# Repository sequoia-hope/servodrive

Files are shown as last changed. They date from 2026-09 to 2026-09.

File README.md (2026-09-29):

# servodrive

A round, motor-mounted servodrive: two Ø65 mm boards stacked on the back of a
brushless motor, with a magnetic rotary encoder on the shaft axis.

**Status: board A captured, placed and routed. 136 parts, 87 nets,
425 pin connections, every one of them made. DRC- and ERC-clean, and
KiCad's own extracted netlist matches the intended one connection for
connection. Re-routed 2026-09-22 with four of the simulation's changes
([below](#the-2026-09-22-changes)); board B is still an outline.
Board S, the single-board variant, captured, placed and routed 2026-09-23
from the same generators, re-routed the same day with TI's buck parts, and
re-placed and re-routed 2026-09-24 with an XT30 for the bus
([below](#board-s-one-board)).**

- **[spec.html](spec.html)** — the specification
- **[index.html](index.html)** — status, decisions, open questions; board A in the viewer (PCB and 3D tabs)
- **[single.html](single.html)** — board S, the single-board variant: captured, placed and routed, with the same viewer (SCH, PCB and 3D)

The pages are styled after Altium 365's workspace: a dark frame with the
project tree on the left, built by `shell.js` from each page's own headings.
The board viewer on the two board pages is
[pcbview](https://github.com/sequoia-hope/pcbview)'s (which began as this
project's own; `tools/regen.py` runs it from `~/Software/pcbview`):
`pcbview.toml` says what it shows, and `python3 tools/regen.py --board a|s`
builds it into `viewer/` and writes it into the page between
`<!-- pcbview:begin -->` and `<!-- pcbview:end -->`.
`viewer/a.html` and `viewer/s.html` are the same viewers filling the window.

Online at <https://sequoia-hope.github.io/servodrive/> (GitHub Pages, from
the root of `main`: the pages are plain files with relative links, and
`.nojekyll` keeps them that way). Served locally: `proj up servodrive`, then
`proj url servodrive` for the address.

## What it is

| | |
|---|---|
| Form | Two Ø65 mm round boards. The motor board bolts to the encoder's 4 × M3 pattern; the power/IO board to six perimeter M2.5. |
| Sections | Three 60° phase cells **adjacent**, 0–180°, then three 60° wedges. The CPU sits in the middle wedge, as far from the switching as a round board allows. |
| Encoder | MT6701 on the shaft axis, SSI to the CPU on the same board. No cable, no line drivers, no encoder port. |
| Bus | 60 V nominal, **12 V minimum**, 80 V silicon, TVS breakdown 71–79 V; XT30 |
| Phase current | **20 A RMS per phase, in bursts** — normal running is well below it, and no fins are planned (§4) |
| CPU | RP2350A, QFN-60 |
| Sensing | Two inline 1.0 mΩ shunts (2 × 2 mΩ) + **INA241A3** at 50 V/V = 50 mV/A, third phase reconstructed; bus voltage; FET temperature |
| Gate drive | EG2103 on a 12 V rail (LCSC C480654, 2,225 in stock, MOQ 5, $0.19) — interlock + 560 ns dead time |
| I/O | USB-C with full PD — a 20 V contract feeds VMOT; full-duplex RS-485 on two chained ports |

## The design point is 20 A RMS, and that word matters

Draft 0.2 used "20 A" for two different quantities: the thermal budget quoted
20 A **RMS per phase**, and the sense chain quoted ±20.6 A **instantaneous**.
Those differ by √2, so the sense chain clipped at 14.6 A RMS — it could not have
closed a current loop at the design point. One number now, and everything is
sized against it:

| | |
|---|---|
| Design point | 20 A RMS per phase — a burst figure since 2026-09-22, not a continuous rating |
| Peak the chain must see | 28.3 A |
| Sense full scale | ±29.0 A, worst-case output swing — 2.5% over the peak, see below |
| Board A dissipation | 10.7 W |
| Heatsink it would need to be continuous | ≤ 6.7 K/W, ≥ 100 cm² of external surface — not built |

## Current sensing

Full scale is set by the shunt. Keep this table, the schematic and the firmware
`SHUNT_RESISTOR` define pointed at each other — the sister project's F-14 is
exactly this drifting apart.

| Shunt (per sensed phase) | Gain | V/A | Measurable range |
|---|---|---|---|
| 1.0 mΩ (2 × 2 mΩ 2010) | 50 V/V | 0.050 | ±29.0 A |
| 2 mΩ (one desoldered) | 50 V/V | 0.100 | ±14.5 A |

Phase C is reconstructed as `Ic = -(Ia + Ib)`. Its two shunt footprints are
fitted with 0 Ω links so all three phases have the same series resistance.

Full scale is against the datasheet's **worst-case** output swing, V<sub>S</sub> − 0.2 V,
not the 0.07 V typical — that is what makes ±29.0 A rather than ±32 A, and it is
the number the design point has to clear. It does, by 2.5%.

**This took three goes.** Draft 0.2's 1.6 mΩ gave 80 mV/A to match the sister
project's firmware scaling, and ±20.6 A of full scale against a 28.3 A peak: it
would have clipped on every cycle above 14.6 A RMS. The first correction, 1.0 mΩ,
used the typical swing figure and had 2.5% of margin, which is not margin. 0.8 mΩ
(2 × 1.6 mΩ) survived the datasheet, and its precision mode landed on the sister
project's 80 mV/A. Then sourcing (2026-09-24) found no 1.6 mΩ 2010 at LCSC or
JLCPCB — 1 and 2 mΩ, nothing between — and the pair became 2 × 2 mΩ: back at
1.0 mΩ and its 2.5%, taken knowingly. The stocked alternative, 2 × 1 mΩ, reads
±58 A at 25 mV/A. Neither mode reproduces the sister project's 80 mV/A now, so
its firmware constants do not carry across.

**And the part number changed.** The 50 V/V grade of INA241 is **A3**, not A2.
INA240 numbers its gains A1 = 20, A2 = 50; INA241 numbers them A1 = 10, A2 = 20,
A3 = 50. Draft 0.2 carried the INA240 mapping across and specified a 20 V/V part
for a 50 V/V job.

## Relationship to rp2350-motor-controller

The sister project at `~/pcb/rp2350-motor-controller` supplies the MT6701
encoder circuit and its mount pattern (`hardware/encoder`), the power-stage part
choices, and a findings register that this board inherits the conclusions of
without inheriting the bugs. §9 of the spec lists which finding produced which
decision here.

Three things worth handing back:

- **F-17 is right, and draft 0.2 of this spec was wrong to doubt it — but not
  for the reason their register gives.** Their E-stop does brake. It brakes
  because `R1`, `R2`, `R21` and `R22` are 10 k pull-downs on both EG3113 inputs,
  and EG3113's LIN is active-low: a pulled-down LIN turns the low-side FET on.
  The driver on its own would coast. The consequence is worth knowing: their
  bridge **hard-shorts the motor at every reset and every power-up**, before
  firmware runs, with no current limit. On a spinning motor that is a braking
  current set only by winding resistance.
- **NCP5183DR2G** is a candidate answer to **F-40** (EG3113 unbuyable, currently
  blocking their orders): SOIC-8, 600 V, 4.3 A source/sink, matched 120 ns
  propagation delays, 50 V/ns dV/dt immunity, AEC-Q100, $0.92 at MOQ 1 with 2,883
  in stock. It gives up EG3113's interlock and dead time, which their own GaN
  evaluation argues they do not lean on. Also worth knowing: **EG2131 and FD2103S,
  the two obvious like-for-like swaps, are both out of stock.**
- **RP2350 erratum E9 reaches the gate driver.** A Bank 0 GPIO can latch around
  2.1–2.2 V, and at reset the pin is an input with a pull-down. Against EG Micro's
  internal 200 k pull-up on LIN that lands the driver input between V<sub>IL</sub>
  and V<sub>IH</sub>. Their pull-downs happen to defeat it; anyone copying the
  circuit without them should size an external pull deliberately.

## The channel interior to the screws

A phase cell is short of **angle**, not of area, and angle costs radius: a
millimetre of arc at R 20 is 2.9°, the same millimetre at R 29.5 is 1.9°. The
cell was 70° wide because small parts sat at small radius — a 1 µF 0805 beside
the gate driver was eating 30° on its own, while both MOSFETs together needed
only 18°.

The six boss pads sit on R 26.9–32.2, and **between them that band is empty**:
the heatsink land owns it on the outward face, and on the motor-facing face
nothing but the lead pads wants it. In the utility wedges that is still true and
the channel is still used. In a **phase** cell it turned out not to be — see
below — and only the clamp diode is left there, beside its own lead pad.

| | 70° cells | everything in the channel | **now** |
|---|---|---|---|
| Phase cell | 70° | 60° | **68°** |
| Utility wedge | 50° | 60° | **52°** |
| Bolt spacing | 70/70/70/50/50/50° | 60°, even | **68/68/68/52/52/52°** |
| In the channel, per cell | — | 6 parts | **1** — the clamp diode |
| Heatsink land | 286 mm² | 250 mm² | **279 mm²** |

**Routing took most of that back, and it was right to.** The middle column is
what the channel bought: 60° cells and an even bolt circle. What it cost only
showed up when the board was routed — a part in the channel can only be
connected if its nets are GND or the phase output, because the phase-output
pour owns B.Cu from R 25.9 to 28.9 beneath it, the heatsink land owns F.Cu from
R 29.2 above it, and the six boss pads cut the outer ring into six arcs. What
is left is a via corridor about 0.7 mm wide, twice per cell. Neither pour can
give the room back: the phase band is already 95 A/mm² at 3.0 mm and cannot
grow inward past R 25.6 without meeting the switch-node band.

So five of the six went back into the cell — the DC-link 100 n pair into the
DC-link row *ahead* of the bulk, where a high-frequency capacitor belongs; the
bootstrap diode beside the capacitor it charges; both input pulls onto the
driver's logic side with the VCC 100 n. Only the clamp diode stays, and its
nets are exactly GND and the phase output.

The cells had to pay for them: 67° is the floor, below which the DC-link row
runs into the perimeter boss, and 68° is what is set. That costs the even bolt
circle — the thing the 60° arrangement was pleasing for. It buys back
**29 mm² of heatsink land**, because the land's half-span is measured from the
cell edge.

Three consolidations paid for it: the per-driver 1 µF VCC bulk became one 4.7 µF
at the power link (three of them on one 0.1 A rail was two too many), the lead
pad narrowed from ±8.5° to ±7° (23 mm², still ample for a 14 AWG lead), and
`Row` learned to dodge parts in *other* rows — two rows that overlap radially
and sit at different angles can collide, and a packer that only looks at its own
row walks straight into them.

## The layout, second pass

The first routed board made 69 of 170 connections, and the diagnosis at
the time blamed the driver ring. Measuring the result said otherwise:
nearly every unrouted connection ended at the RP2350. In3, the only signal
layer that crosses the board, was almost empty, because nothing could get
out of the QFN to reach it. Three things were true of that board and are
not of this one.

**The QFN had no room to fan out.** A 0.4 mm pitch, 0.2 mm-wide pads, and a
via that is 0.46 mm across with 0.15 mm around it: a via per pin does not
fit in place, and it does not fit in two rows either. With 0.15 mm stubs it
takes four staggered rows, 2.9 mm deep, on every side — and the chip sat
0.3 mm from the parts either side of it, 0.8 mm from the row beyond it,
with its decoupling on the back directly under the pins where the vias had
to land. The CPU wedge is rebuilt around a clear band: the chip at R 21.15,
nothing within 2.9 mm of its pads on the front except the regulator
cluster (below), the six IOVDD 100 n on the back in two columns beside it,
the crystal in a row at R 29.9, and the flash turned so both its pad rows
face somewhere a via can go, with its own 100 n and the BOOTSEL resistor on
the back directly beneath its body. The signal header moved in to R 25.15,
where all twenty of its signal pads can take an escape via on the side away
from the edge.

**The FET gate pads faced the wrong way.** The gate is at one end of the
TDSON-8's source-pad row, and with the row pointing outward the gate sat at
R 27.9, walled in by the switch-node pour on three sides and the heatsink
land on the fourth. Both FETs are turned 180°, which swaps their sides, and
the gate pads are at R 24.4 facing the driver row across an empty 1.5 mm.
The gate resistors and input pulls are 0402s lying tangentially, so HO and
LO reach a pad at their own radius and the far pad points at the gate; the
bootstrap cap is a 0603 with its SW pad over the switch-node pour, so it
takes a via.

**The sense row on the back is arranged for arcs, not for a router.** The
amplifier is at the cell's centre with its SNSP pin, the switch-node-side
tap and the filter cap all clockwise of it within 0.4 mm of R 18.4, so
that SNSP is one arc between the amplifier's pad rows with a spur down to
each pad, and SNSN is a second arc beside it to the filter cap, a via at
the amplifier and a via in the tap at the shunt, and one run on In3
between them. The gate bleeds moved from that row to directly beneath the
gate resistors: the high side's radial under its resistor, the low side's
further out under the gate's own radial track, each with one via through
both pads. The NTC moved inside the row where its pad can take a via. The
flash is turned so that each pad row's radial order is the chip's QSPI pin
order along its side and the In3 runs between them do not cross.

**Every 20 A pad takes a via, and the router never sees those nets.** The
shunts moved from either side of the cell to side by side under the
switch-node island, between the two FETs' via clusters — nowhere else on
the back is clear of the DC-link caps' vias coming through from the other
face — with the SW pads over the switch-node pour and the PHASE pads in the
phase-output pour, the lead pad directly beyond. The sense taps sit beside
them, the clamp in the channel beside the lead pad where the pour reaches
out to it. The switch-node pour on B.Cu comes in to R 20 so the driver's VS
pin, the bootstrap cap, the bleed and the tap all stitch. +3V3 is a plane on
In2 that is now the whole centre disc as well as the CPU wedge, so each
cell's sense amplifier taps it with a stub. With all of that
stitched, `tools/deadcheck.py` proves it and `route.py` takes VBUS, the
switch nodes, the phase outputs and +3V3 away from the router: pours become
keepouts, pads lose their net and get a halo the width of their clearance
class. It cost the cells 0.9 mm of FET spacing, a 1206 DC-link bulk cap
instead of a 1210 (the 1210 ran into the perimeter boss), and a SOD-323
bootstrap diode.

### The RP2350, from the reference design

The chip's regulator and decoupling are Raspberry Pi's, copied from the
RP2350A minimal design (RP-006440) in the chip's own frame to the 0.05 mm:
the 3.3 µH 2016 inductor 3.8 mm from VREG_LX with the VIN, DVDD and AVDD
4.7 µF stacked beside it, the two by the inductor on the reference's own
small-pad 0402 footprint because the switch node's neck passes between
their pads; 33 Ω into VREG_AVDD; 27 Ω in series with each USB line; five
small pours around the regulator pins; a ring of 1V1 copper under the chip
joining the four DVDD pins, which the fan-out tool reaches with a stub from
each; and the reference's own two F.Cu tracks, VREG_AVDD out to its RC and
DVDD pin 50 out to the regulator's output pour (the second is only laid if
the fan-out beside it leaves the room, and here it does not, so the ring
and the output pour meet through a via each and a run on In3 that the
fan-out tool lays itself, dodging the via field). Two of the pours turned
out not to fill under the 0.15 mm clearance this board runs — between two
0.4 mm-pitch pads a pour is 0.3 mm wide and breaks at their corners — so
VREG_LX gets a 0.15 mm track as well, threaded between the VIN capacitor's
pads the way the reference's pour is.

Three things capture found while doing it, all in the netlist rather than
the layout:

- **The bootstrap diode was backwards.** `Device:D` numbers its pins
  1 = cathode, 2 = anode, and so does the footprint; the netlist had the
  cathode on +12V. A bootstrap diode charges the cap *from* the rail.
- **VREG_AVDD was tied straight to +3V3.** The reference feeds it through
  33 Ω with its own 4.7 µF.
- **USB had no series resistors.** 27 Ω each, as the reference.

The crystal's load caps stay at 27 p where the reference uses 15 p: the
reference's crystal is a different part with a different CL, and the value
is the crystal's to decide.

## Layout

```
tools/sexp.py        a reader/writer for KiCad's s-expressions
tools/geometry.py    every dimension and every derived number; regenerates img/*.svg
tools/placement.py   the board-A floorplan, and the checks that keep it legal
tools/placement_s.py board S, the single-board variant: its floorplan (layout()),
                     drawn to img/board_s_*.svg and single.html's tables
tools/schematic.py   the board-A netlist, and the sheets it emits
tools/schematic_s.py board S's netlist, built from schematic.py's own functions
tools/gen_boards.py  emits the KiCad projects from the three above; --board s
                     emits board S alone
tools/stitch.py      puts a via in every pad that sits over its own plane
tools/fanout.py      the copper the router could not make: the RP2350's escape
                     vias, the gate and sense arcs, the escapes, the plane taps
tools/deadcheck.py   proves every pad on a net route.py demotes already
                     touches copper of its own net
tools/padpos.py      pad centres of a placed Part, polar, without a board
tools/finish.py      a maze router over the board's free space, for whatever
                     freerouting gives back still in pieces
tools/route.py       hands the rest to freerouting, headless, and brings it back
tools/regen.py       remakes what the pages show after gen_boards.py or
                     route.py (both run it): the board viewer (pcbview build),
                     board S's build status, board S's simulation
pcbview.toml         the board viewer: which boards and pages, the sheet names,
                     the layer notes, the stand-in 3D models, the LCSC table
hardware/
  parts/3dmodels/    two STEP models the footprints name and KiCad's library
                     lacks, and one it has but kicad-cli cannot mesh, flattened;
                     stand-ins for the 3D viewer, mapped in pcbview.toml
                     (sources in its README)
  parts/lcsc.csv     the LCSC numbers chosen so far, by value and footprint, for
                     the 3D viewer's part pane; a part not in it has none yet
  parts/             two symbols copied in, three DERIVED (EG2103, INA241A3,
                     W25Q16JV), two copied from the RP2350A reference design
                     (the 2016 inductor, a small-pad 0402) and five GENERATED
                     footprints (the FET with 16 thermal vias for the low side
                     and 20 for the high, heatsink boss, heatsink land, phase pad)
  motor_board/       servodrive_A — 6 layer, 2 oz outer, 136 parts, 87 nets
  power_board/       servodrive_B — 4 layer, 2 oz outer, outline only
  single_board/      servodrive_S — board S, 6 layer, board A plus board B's minimum
img/                 generated drawings — do not edit by hand
viewer/              built by pcbview — do not edit by hand: a/ and s/ (sch/,
                     layers/, 3d/ with board.glb and parts.json), assets/ (its
                     scripts, viewer.css, three.js), a.html and s.html
shell.js             the frame every page shares, after Altium 365: top bar, the
                     PROJECT tree read off each page's headings, the sheet bar
style.css            the one stylesheet, A365's palette (sim/report uses it too);
                     the viewer's own is viewer/assets/viewer.css
vendor/fonts/        Inter, latin and greek (OFL)
spec.html            the specification
index.html           project status
```

The three tools are checked against each other before anything is written:
`gen_boards.py` will not emit a board if the floorplan overlaps itself, or if
any part is on the board and not in the netlist, or in the netlist and not on
the board, or if their footprints disagree, or if a symbol pin has no net.

Run `python3 tools/geometry.py` after changing any dimension, then
`python3 tools/gen_boards.py --force` to re-emit the boards. `gen_boards.py`
refuses to run at all if `placement.py`'s checks fail, so a board that overlaps
itself cannot be written.

`--force` rewrites the boards from scratch, which now means **throwing away the
routing**. Without it `gen_boards.py` keeps the existing `.kicad_pcb` and only
re-renders. `--force` also runs the stitcher and the fan-out, so the board it
writes is already half made; after it, re-run `python3 tools/route.py --rounds 4
--loose` for the rest. The moment you move a part or a track in KiCad by hand,
stop using `--force` at all.

## Hardware

Both projects are KiCad 9, DRC- and ERC-clean. Board origin is the shaft axis on
both, so the stack aligns.

| | Board A | Board B |
|---|---|---|
| Stackup | 6 layer, 2 oz outer / 1 oz inner | 4 layer, 2 oz outer |
| Diameter | Ø65 mm | Ø65 mm |
| Motor mount | 4 × M3 at (±12.5, 0), (0, ±9.5) | — |
| Stack mount | 6 × M2.5 at R = 29.5 | 6 × M2.5 at R = 29.5 |
| Placed | 136 parts, 78 front / 58 back, 10 DNP | — |
| Captured | 136 components, 87 nets, 425 connections | — |
| Routed | 1361 track segments, 278 vias, all 425 connections, **DRC clean** | — |

The F.Cu → In1 prepreg is **0.1 mm**, and that is a load-bearing number, not a
stackup detail: it is what puts the ground plane under the commutation loop and
holds loop inductance at 0.39 nH of PCB, 2.0 nH all in, 1.7 V of overshoot on
80 V silicon.

Design rules: 0.15 mm track and clearance everywhere except the 60 V nets, which
get 0.4 mm; vias 0.5/0.20 signal, 0.6/0.30 power, 0.8/0.40 phase; **0.5 mm
hole-to-hole**. That last one is deliberate — JLCPCB fills and copper-caps
via-in-pad for free on 6-layer boards, which is what lets the pad centres be
holes at all, but it wants 0.5 mm between them, and the sister project's F-48 is
the cost of discovering that after 253 via pairs were already too close.

Two of those numbers moved during routing, and both were wrong before:

- **0.15 mm, not 0.20, on the power and analog classes.** A 0.65 mm-pitch
  VSSOP-8 has 0.15 mm between adjacent pins, so a 0.20 mm class made every
  INA241 a clearance violation that no layout could fix. 0.15 is also JLCPCB's
  floor for 2 oz outer copper, so nothing is given up.
- **0.20 mm drills on the 0.5 mm vias, not 0.25.** The annular ring is
  (diameter − drill) / 2, so 0.25 left 0.125 mm against this project's own
  0.13 mm minimum. The default via was illegal under the default rules, and
  nothing noticed until there were vias on the board to check.

Verify after any change:

```sh
python3 tools/placement.py       # floorplan: overlaps, bounds, cross-layer
python3 tools/schematic.py       # netlist, and that it matches the placement
python3 tools/deadcheck.py hardware/motor_board/servodrive_A.kicad_pcb
python3 tools/route.py --rounds 4 --loose   # route headless, import, finish, DRC
cd hardware
kicad-cli pcb drc motor_board/servodrive_A.kicad_pcb
kicad-cli sch erc motor_board/servodrive_A.kicad_sch
kicad-cli sch export netlist --format kicadsexpr -o /tmp/n.net \
    motor_board/servodrive_A.kicad_sch     # then diff it against schematic.nets()
```

That last one is the check worth keeping: KiCad's own extracted netlist against
the one this repo intended, net by net and connection by connection. It is how
the sub-symbol naming bug below was caught, and it is the only thing that proves
the labels actually connect what they look like they connect.

## Routing

Most of board A is not routed and never will be. GND is two solid inner
planes, VBUS is a sector of a third, +3V3 is the rest of that third — the
CPU wedge and the whole centre disc — and each switch node and phase output
is a pour on F.Cu and B.Cu, because 20 A does not go down a track and
IPC-2152 wants about 6 mm of 2 oz copper for it. What is left is the
signals, and those go to freerouting — less the ones it turned out to do
badly, which are made first, as copper, and taken away from it.

Five tools do the rest, and freerouting is the fourth of them rather than
the whole story. They all run from `gen_boards.py` and `route.py`, so the
board is still reproducible from `geometry.py`:

- `tools/stitch.py` puts a via in every pad that sits over a plane or pour
  of its own net. 104 of them.
- `tools/fanout.py` makes the connections the router could not. It escapes
  the RP2350: a 0.15 mm stub from the centre of every one of its sixty
  pads and a via at the end of it, in planned staggered rows, the stub
  threaded through the rows in front of it. It joins the four DVDD pins to
  the 1V1 ring under the chip. It wires each FET's gate to its gate
  resistor — radially in from the gate, an arc along the band between the
  driver row and the FETs, radially in to the resistor's pad — and puts a
  via through that pad into the gate bleed's pad directly beneath it, so
  the whole gate net is copper. It wires SNSP and half of SNSN as arcs
  between the sense amplifier's two pad rows on the back, and joins SNSN's
  other half on In3. It gives the flash, the signal header and the
  amplifiers' remaining pads a stub and a via each. And it taps every pad
  on a plane net that is not over its plane — +3V3 mostly, and the few
  ground pads a via would not fit in — with a stub to a via that is.
- `tools/deadcheck.py` then proves that every pad on VBUS, the three switch
  nodes, the three phase outputs and +3V3 already touches copper of its own
  net.
- `route.py` hands what is left to freerouting: it takes the demoted nets
  and every net already finished away from the router entirely — their
  pours become keepouts, their In2 planes go, their pads lose the net and
  get a keepout halo the width of their clearance class.
- `tools/finish.py` is a maze router, and it goes last, on what the router
  gives back still in pieces — deterministically, at 45 degrees, every
  segment checked against the same clearance test the fan-out uses, and
  allowed to move the router's own wires to do it.

Every track and via the tools make is **locked**. That is not a courtesy
to the KiCad user: it is how `route.py` tells the tools' copper from the
router's on the way out and on the way back, below.

### The maze

The last few connections are not hard because the board is full. They are
hard because they are *last*: the lanes out of the QFN's via field are
spent on whichever nets reached them first, and the ones left over cannot
be routed by anything that will not move what is already there.
`tools/finish.py` is that: a maze router that knows the whole board, and
rips up when it has to.

It rasterises. One bitmap per routable layer —
F.Cu, In3 and B.Cu; In1 and In4 are ground and In2 is the power planes — at
0.05 mm, every foreign shape drawn as it is and then grown by the clearance
it wants, 0.15 mm or 0.4 for the 60 V nets, by a distance transform. Then
A\* from one piece of the net to the other, eight-connected so that every
step is 45 degrees, with a via as a move between layers wherever a via
would fit. The path that comes back is a chain of cells, which is not what
anyone wants on a board, so it is folded back into as few segments as the
free space allows: from each point, the farthest point it can be joined to
by one straight run and one diagonal.

Two things it has to know that KiCad's clearance rules do not cover, and
both were found by DRC after the first run:

- **The board edge.** The clearance test is between copper and copper; the
  outline is neither. The maze knew the edge and the simplifier did not, so
  it cut a corner 0.4 mm outside the board — twice, on two layers. The
  simplified path answers to the grid as well as to the clearance test now.
  (And the edge radius comes from the outline circle rather than from the
  board's bounding box, which is bigger by half the outline's 0.1 mm
  stroke.)
- **A bare drill.** An M3 mounting hole is NPTH: it has no copper, so no
  copper clearance rule mentions it, and `min_hole_clearance` is the only
  thing keeping a track off it. Seven tracks ran within 0.16 mm of the four
  mounting holes before the grid was told about drills.

The grid is a rasterisation, so it is conservative by 0.03 mm — a little
over half a cell, which is what a drawn boundary is worth. What it proposes
is still checked exactly, segment by segment; what the exact test rejects
is punched out of the grid and the route planned again. In practice one
step in seven hundred comes back, short by a micron, and the detour costs
nothing.

When a net cannot be made at all, the maze rips up: every unlocked track
near the gap — the router's copper, never the tools' — comes out by whole
nets rather than by the segments that happen to fall in the box, the
connection is made, and then the nets that were displaced are made again,
longest first, each of them allowed to rip up in turn. If any of them
cannot be, the whole attempt is undone and the box grows.

**Undoing it is the part that was wrong.** The first version recorded which
items were on the board and which had been taken off, and undid an attempt
by deleting everything that had appeared since and putting the recorded
ones back. That is correct until an attempt rips up inside an attempt: the
inner one puts its copper back as *new* items, the outer one then deletes
them as things that were not there before, and they are in nobody's
record. The log said four connections made; KiCad said forty-one
unconnected. The undo copies the whole board now, and there is a guard
around the whole pass: KiCad's own count of what is unconnected, before
and after, and if the maze has not improved it the pass is thrown away and
the board stands as the router left it.

**Order matters more than either router.** Given the whole board first,
with only the fan-out's copper in the way, the maze makes 49 of the 61
nets and leaves 12 — and freerouting, handed a board full of locked
copper, then closes one. Given what freerouting leaves, six connections,
it makes four. Seeding it with those six by name and running it first came
back with nine. It does not matter which nets get the lanes out of the via
field; it matters how many lanes there are.

### Why the fan-out is a tool and not a pass

A 0.4 mm-pitch QFN cannot take a via per pin in place. The pads are 0.2 mm
wide with 0.2 mm between them, a via is 0.46 mm across and wants 0.15 mm
around it, and every via row that goes in front of the chip takes lane
width from the stubs that still have to pass it. The arithmetic: with
0.15 mm stubs, a row of vias every fourth pin leaves 0.84 mm between two of
them, and the three stubs that pass through need 0.75. That is the whole
margin, 0.09 mm, and it is why the fan-out is four rows deep.

It is also why the stubs are threaded rather than bent. A stub passing a
neighbour's via steps 0.06 mm aside for the length of that via and comes
back; held aside across a whole row-to-row interval, two neighbours passing
vias on opposite sides of themselves met in the middle, 0.03 mm too close.
The search is a small dynamic programme over (waypoint, lateral offset)
that strays from the pad's axis as little as it can, and it finds 51 of the
52 vias in about five seconds.

### The via in the pad

For every SMD pad whose net has a filled zone on some other layer directly
beneath it, the stitcher puts a via in the pad. That is via-in-pad, which
JLCPCB fills and plates over for free on six layers — which is the only
reason a pad centre is allowed to be a hole. It places 104 and
leaves 146 connections to the fan-out and the router.

It is worth doing by hand because the router does it badly. Given the board
whole, freerouting queued all 112 ground pads as isolated, threw the vias
away and ran 0.2 mm traces across the top and bottom layers instead — 92 of
the 177 connections it could not finish on the first board were this.

Two rules matter and the first version of the stitcher got the second wrong:

- the via's pad has to fit inside the SMD pad, and its hole has to keep
  `min_hole_clearance` from foreign copper;
- **the via's pad has to clear foreign copper on every layer, not just the
  pad's.** A through via's annulus exists on all six. Fitting inside an F.Cu
  pad says nothing about what the same copper does on B.Cu, and checking
  only the drill put 33 clearance violations on the board.

### What the round trip got to decide

Everything below was found by measuring the result, not by reading about it.

- **Freerouting does not treat a Specctra `plane` as connecting anything.** So
  ground is taken off the table before export: the planes go, the net goes, and
  In1/In4 are declared `power` layers, which is Specctra's way of saying *not
  for routing*. The pads stay, as obstacles with no net, which is exactly what
  they are to a router that is not routing them.
- **A `plane` is not an obstacle either.** `ignore_conduction` defaults to
  true, so given the 20 A pours as planes the router lays a foreign track
  straight through them and KiCad cuts the pour around it. Every pour is a
  keepout by the time the router sees it, and every pad on those nets is
  stitched to its pour first.
- **A protected via is protected on its pad's layer, by the pad, and nowhere
  else.** The ground vias are removed from the DSN and each leaves a
  keepout on the four signal layers, or the router runs a trace under the
  pad on In3 and the via lands on it when the stitch is restored.
- **KiCad's SES import takes a via's diameter from the Specctra padstack and
  its drill from the netclass.** Those are not the same thing. A stitching via
  in a pad too small for the 0.8/0.40 the Phase class wants is 0.46/0.20, and
  it came back 0.46/**0.40** — a 0.03 mm annular ring, fifteen of them. The
  diameter is the honest half of the pair, so `route.py` rebuilds every drill
  from it after import.

  The first attempt at this was to stop offering the 0.46 padstack in the DSN,
  and it made things worse in a way worth recording: freerouting then wrote a
  session that *used* that padstack for the pre-placed vias without *defining*
  it, and KiCad's importer rejected the whole file with no message at all.
- **Specctra has no hole-to-hole rule.** `via_via` and `via_pin` copper
  clearance stand in for it: 0.3 mm between two 0.5/0.20 vias puts their holes
  0.5 mm apart, which is the rule this board is built to. And a class with a
  rule of its own does not inherit them from the structure rule — measured
  as two vias on Analog-class nets 0.48 mm hole to hole — so every class
  rule carries both.
- **The router routes right up to the boundary it is given.** The outline is
  pre-inset by `min_copper_edge_clearance` before export; the board is a circle
  about the shaft axis, so the inset is exact.
- **`PAD::GetLayer()` answers F.Cu for a pad on a flipped footprint.** Only the
  layer set knows. Believing it put fifteen vias between a B.Cu pad and a B.Cu
  pour, which DRC reports as "connected on only one layer", and is.
- **KiCad's DRC report names items by uuid**, and a library footprint
  embedded verbatim carries the library's pad uuids, so six FETs shared
  them and the unconnected list named the wrong FET's gate for three runs.
  Every embedded item gets a uuid of its own now.

### What freerouting turned out to do

All of it measured, most of it by reading the router's log and some of it
by reading its bytecode, after four runs in a row stopped at the same
thirty connections.

- **A wire touches a pad only if it ends on the pad's centre, exactly.**
  `Trace.get_normal_contacts` compares the wire's end with
  `DrillItem.get_center()` using `equals`. Freerouting computes that centre
  itself, from the placement rotation, in doubles rounded to its 0.1 µm
  grid; KiCad writes wire coordinates to the whole micron. So a stub that
  started 0.05 mm inside its pad was a separate island to freerouting, and
  so was one that started on the pad's centre: it then queued 119
  connections between a pad and its own stub, could insert none of them,
  and spent every pass's ripup budget on them. `route.py` now rewrites
  every wire end within 30 µm of a pin or a via of its net to the centre
  freerouting will compute. The count of incompletes it starts from fell
  from 196 to KiCad's own.
- **In 45-degree mode it cannot leave a pad that is not on the grid.** Its
  search tree wraps a tilted pad in the pad's bounding octagon. On a round
  board every pad is tilted; for the FETs' 0.85 × 0.5 mm gate pads the
  octagon plus clearance runs into the halos beside them ("no accessible
  expansion doors", every gate, every pass), and for the flash's 0.5 mm
  pitch and the amplifiers' 0.65 it overlaps the neighbours. Free-angle
  mode is exact and routes them, and a pass of it took twenty-five minutes
  where a 45-degree pass takes five seconds — so those pads are not left
  to it.
- **A protected wire is a bad target.** The maze search reaches the stub
  before the via at its end, and a junction into a protected trace cannot
  be inserted ("the new connection could not be inserted", 791 times in
  one run); a three-segment protected polyline joined twice sends
  normalization round a loop for ever (32,000 "max normalization depth"
  lines in forty seconds, in a board of four pads; the gate arcs did the
  same to the real board, pass 1 never finishing). So the router is not
  shown the stubs at all: a pin that has its stub and its via leaves its
  net's pin list, the stub becomes a keepout, and the net's end is the via —
  a circle, on the grid at any angle, nothing to tee into. A net with no
  pins left and two vias routes fine. The nets the fan-out finishes
  outright — the gates, bleed and all, SNSP, SNSN, the 1V1 link — are
  demoted like the 60 V ones, by KiCad's own DRC just before the export.
  Passes went from thirty-five seconds to five.
- **Its last pass can undo what its earlier passes did.** An attempt that
  rips up neighbours and then fails does not put them back, the pass-end
  tally does not count them, and the session comes back with three or
  seven nets that have their vias and no wire. So `route.py` runs
  rounds: each exports the board as it stands and routes what is left.
- **A locked track exports as `(type fix)`, an unlocked one as
  `(type route)`**, and that is the only handle there is on *my copper
  versus the router's* across the round trip. A strict round protects
  both. The rounds after the first are *loose*: only the tools' copper is
  protected, the router's own earlier wires stay `(type route)` and are
  its to move, and only nets whose copper is all the tools' are demoted.
  It does not rescue the last few nets — told it may move its earlier
  wires, freerouting reports "board state has not changed since pass #1"
  and stops, because every alternative it can see costs more than what it
  has — but it is what makes the rounds safe to repeat. And since KiCad's
  session import keeps a locked item and the session carries its own copy
  of some of the protected vias, moved by up to 25 µm — the difference
  between the fan-out's 0.1505 mm clearance and a violation — the copy
  goes and the original stays, and the router's tracks end inside its pad
  regardless.
- **A class naming a net that no longer exists is fatal, silently.** Take a
  net out of the network but leave its name in a `(class ...)` list and
  freerouting reads nothing, reports one unrouted net and writes an empty
  session.
- **`-inc`, the ignore-net-classes flag, does nothing in 2.2.4 headless.**
  Measured: identical counts with and without it.

### Where it got to

**1361 track segments, 278 vias, every one of the 425 pin
connections made.** DRC finds nothing, ERC finds nothing, KiCad's own
exported netlist matches the intended one net for net, no foreign copper
anywhere under the heatsink land, every annular ring legal, and no
right-angle corners. 212 of the vias are the tools' —
112 stitched into pads, the rest the fan-out's — and freerouting
made the other 66. That is the 2026-09-22 board; the one before it was
1351 segments and 283 vias, and both finished in freerouting's first round.

| | 60°, parts in the channel | 68°, first pass | 68°, 2026-09-11 | **68°, this board** |
|---|---|---|---|---|
| Connections beyond a via in the pad | 170 | 170 | 146 | 143 |
| Left open | 74 | 101 | 0 | **0** |
| DRC | clean | clean | clean | clean |
| Right-angle corners | 2 | 0 | 0 | **0** |

The first routed board blamed the driver ring for the 101 it could not
make. It was wrong: the ring got busier, but nearly every one of the 101
ended at the RP2350, and the layout section above says what was done about
that.

### The 2026-09-22 changes

Four of the simulation's hand-back items, taken together so that the routing
was thrown away once:

- **Every low-side barrel reaches B.Cu.** The switch-node pour on the back
  stopped at R 25.2 and the low side's 4 × 4 array runs out to R 28, so only
  the inner row touched it — the other twelve sat in the clearance between it
  and the phase-output pour, joined to F.Cu and nothing else. The pour now has
  a tab over the array, cut in the FET's own frame (`gen_boards.via_tab`): to
  the centres of the end columns tangentially, so the fill reaches every pad
  and no further, and out past the outer row radially, where clearance holds
  it off the motor-lead pad.
- **The high side has twenty barrels** (`TDSON-8-1_ThermalVias_HS`): a fifth
  row at 0.905 mm, the array moved 0.15 mm along the pad away from the source
  pins, and the via pad trimmed from 0.80 to 0.78 mm so five rows fit the
  4.41 mm pad. It is the only way to add barrels. A fifth *column* lands
  inside the shunts' courtyards on the back under either FET, and a fifth row
  under the low side comes 0.14 mm from the lead pad.
- **An RC snubber per cell**, 2.2 Ω + 470 pF C0G, DNP: `R{n}13` and `C{n}09`
  on the back under the high side, tangential, the capacitor's ground pad on
  a via, the resistor's other pad on the switch-node pour, their middle node
  (`SNUB_x`) a small pour of its own in the Phase class. 0603, not the
  simulation's 0805: an 0805 pair's corner comes within 0.25 mm of the DC-link
  capacitor's VBUS via, and radial they take the room the fifth row needs.
- **A Ø6 magnet.** Nothing on the board reads `MAGNET_D`, so the hand-back's
  "the keepout moves" was wrong; only the drawings changed.

And one of the decisions made the same day reached the board: **both input
pulls of every driver go to GND**, so a reset brakes. That took the LIN
pull-up's +3V3 via away from the thermistor beside it, whose plane tap had
been sharing it; the fan-out's plane taps gained a last resort for
two-terminal parts (`fanout.dogleg`) — a first leg at any of the eight
45-degree headings, then straight to the nearest via that lands on the
plane — and only for the pads the ordinary taps cannot make, so every other
tap is laid exactly as before.

What it bought, from the simulation's conduction solver (P3) re-run on the
routed board in a scratch copy — `sim/results/` itself still describes the
board before:

| | before | after |
|---|---|---|
| Low-side barrels joined on B.Cu, per cell | 4 of 16 | **16 of 16** |
| Busiest low-side barrel, 20 A RMS | 5.16 A rms | **2.82 A rms** |
| Busiest high-side barrel, 20 A RMS | 2.42 A rms (16) | **2.10 A rms** (20) |
| Switch-node copper, cell A | 0.74 W | 0.61 W |
| Switch-node current density, p99.9, B.Cu | 259 A/mm² | 199 A/mm² |

Better, and still over the 2 A a 0.4 mm barrel is allowed at a continuous
20 A: the current crowds into the barrels nearest the shunts, so four times
the barrels bought less than twice the margin. By the same guideline the
low-side arrays carry about 14 A RMS continuously and the high side 19 A;
above that is burst territory, which is how the drive is now meant to be used.

### The last three, and why they were arithmetic

For a long time the board stopped at two or three open connections, and
they moved around. Freerouting left six; the maze made four of them.
Running the maze first instead, on a board with only the fan-out's copper
in the way, made 49 of the 61 nets and left 12 — and freerouting, handed a
board full of locked copper, then closed one. Seeding the maze with the six
by name and running it first came back with nine. Three routers, three
different sets of survivors, the same order of magnitude: that is the shape
of a capacity limit, not of a search that needs more time.

The capacity was the lanes out of the QFN's via field, and it was
countable. The escape vias sat in four rows 0.71 mm apart. A 0.15 mm track
passing *radially* between two rows needs 0.23 mm to clear a via's pad,
0.15 mm of clearance and half its own width, on each side: **0.91 mm
between row centres, and there was 0.71.** So there was no radial lane
anywhere in the field, and all sixty escaped signals had to leave through
the tangential gaps within a row — 1.14 mm between two vias, which holds
two tracks. The last few connections were the ones that ran out of them.

Two lines of the fan-out closed the board:

- **The outermost row moved out by 0.20 mm** (`LANE` in `tools/fanout.py`),
  which makes that one gap 0.91 and buys a radial lane the whole way round
  the chip for 0.2 mm of extra depth. A lane between *every* pair of rows
  would want 0.95 mm pitch, 3.5 mm of fan-out against today's 2.8, and
  another 0.6 mm of clear band on every side of the chip — the wedge
  rebuild again, one notch further. It was not needed.
- **The pins the planned rows could not place get a second try** from the
  generic escape, which is not fussy about which row a via lands in. That
  was one pin, LED_R — and a QFN pin without a via is a pin no router can
  ever leave, because the pads are 0.4 mm apart and a track with its
  clearance needs 0.45. One pin, one connection, and it was the last one.

With both, freerouting finished the board in its **first round** and the
maze found nothing left to do.

### 45 degrees, and no stair steps

The imported tracks are measured, not assumed: `route.py` buckets every
segment by direction and counts corners where a horizontal segment meets a
vertical one. Any that survive are chamfered — both new endpoints lie on
the old track and the diagonal between them lies inside the corner it
replaces, so a chamfer only ever removes copper and can never create a
clearance violation.

What is on the board: **345 segments at 45°, 361 orthogonal,
645 at neither**, and the last are the tools' — pad exits along a
rotated pad's own axis, the gate arcs, the sense arcs, and a fan-out that
is radial to a chip at 270° on a board where nothing is on the grid.
**No right-angle corners at all**, and 9 tees — a branch leaving a
run at 90°, which is a junction and not a stair step.

Four things are repaired after the round trip, and all four are
deterministic passes rather than judgement:

- **degenerate segments.** Specctra leaves sub-micron stubs — a corner point
  emitted twice, half a micron apart — and each turns a clean 45° bend
  into a right angle that cannot be chamfered because there is nothing to
  cut.
- **hole-to-hole.** Specctra cannot express the rule, so a few drills come
  back 20–40 µm too close. Narrowing one via's drill changes no geometry
  at all; where that is not enough the via is nudged, checked against
  everything around it.
- **unused vias.** An escape the router did not use — it found its own way
  to the pad — is copper on one layer, and KiCad is the judge of that: the
  via goes, then the stub that led to it.
- **pour islands.** Routing cuts the ground pours into pieces; each one that
  has no via of its own gets one, and the tools' plane taps are laid again
  wherever the round trip lost one.

## The schematic

Board A is captured: 136 components, 87 nets, 425 pin connections, across four
hierarchical sheets. ERC is clean — zero errors, zero warnings — and KiCad's
exported netlist matches `schematic.nets()` exactly.

It is **generated, and drawn with labels rather than wires**: parts on a grid,
grouped by function, a 2.54 mm stub and the net's name on every pin. That is an
honest description of what it is. Routing wires between 115 parts automatically
produces something worse to read than a table, and the value here is a netlist
that cannot drift from the placement — the designators, the footprints and the
DNP flags are one source of truth, checked both ways on every build.

What capture found, in the order the schematic asked for it:

- **The RP2350A was missing everything it cannot run without.** No inductor on
  `VREG_LX` for the core buck, no cap on DVDD, no filter on `ADC_AVDD`, no
  pull-up or cap on `RUN`, no series resistor on `XOUT`. Eight parts, now placed
  — the decoupling on the back, directly under the power pins.
- **The bus divider was wrong by 2.3×.** 50 k / 5.1 k puts **5.5 V** on a 3.3 V
  ADC pin at a 60 V bus. It is now 112 k / 4.7 k — 2.42 V at 60 V, 3.18 V at the
  TVS clamp — and the high leg is **two** resistors, because a 0603 is rated
  50 V working and the bus is 60.
- **`FAULT_n` floated.** The overcurrent comparator is an open question, and an
  unfitted comparator leaves a CPU input with nothing on it. A 10 k pull-up is
  the "not fitted" state.
- **`USB_VBUS_DET` arrived from board B and went nowhere.** It is on GPIO22 now,
  which was spare.
- **PD's I²C was on two pins that are not an I²C pair.** SDA on GPIO19 and SCL
  on GPIO20 are I2C1's SCL and I2C0's SDA; the FUSB302 could only have been
  reached by PIO. I2C0 is 20/21, so the three PD names were rotated — INT on
  19, SDA on 20, SCL on 21 — on the routed copper itself, and J9's pins 9, 10
  and 12 went with them. No re-route; DRC, ERC and the netlist diff are clean
  after it. Found 2026-09-22 while planning a single-board variant.
- **The signal link is 20 signals and 8 grounds**, not the "18 + 10" the spec
  claimed. The count was never done.
- **The phase TVS were in the parts table and not on the board.** Three added.
- **The MOSFET's symbol and its footprint disagreed.** KiCad's own
  `Transistor_FET:BSC030N08NS5` numbers its pads 1–3 source, 4 gate, 5 drain;
  the sister project's `PowerPAK_SO-8_123` numbers them 1/2/3 = S/G/D. Using
  both would have wired every FET wrong. Board A now uses KiCad's matched
  symbol/footprint pair — which also has a larger drain pad, so the thermal via
  array got easier.

### Seven things the KiCad file format got to decide

All seven were found by DRC, ERC or the netlist diff, and fixed in the
generator rather than worked around:

- **Every pad needs its own absolute angle.** KiCad does not derive pad
  orientation from the parent footprint. Leave it out and pad *positions* rotate
  while pad *shapes* do not — on a round board, where almost nothing sits at 0°,
  that is every fine-pitch part's copper turned the wrong way. It showed up as a
  1.27 mm-pitch SOIC-8 reporting 0.0000 mm between adjacent pins at 90° and
  nothing at all at 45°.
- **A custom pad needs the angle too**, separately, or its primitive polygon is
  evaluated unrotated — which put the heatsink lands off the board edge.
- **`net_settings.classes` wants `microvia_*`, not `uvia_*`, and a `priority` on
  every class.** Get it wrong and KiCad discards the whole list and silently uses
  its factory 0.2 mm netclass. The symptom is DRC quoting a clearance rule that
  appears nowhere in the project file.
- **`lib_footprint_mismatch` is muted**, and only that one. Every footprint is
  embedded verbatim from its library, but KiCad re-derives geometry through the
  placement angle, so a part at 37.5° mismatches an identical library copy.
  Checked in isolation before muting.
- **A schematic's `lib_symbols` names units by the *bare* symbol name.** The
  entry is `Device:R`, but its units are `R_0_1`, not `Device:R_0_1`. Get it
  wrong and the sheet fails to load — and in a hierarchy that failure is
  **silent**: the root still opens, ERC still reports zero violations, and the
  netlist comes out empty. Nothing but exporting the netlist and counting would
  have caught it.
- **A sheet has two different uuids.** The `(uuid)` inside the `.kicad_sch` is
  the file's; the path a symbol instance quotes is `/` plus the uuid of the
  `(sheet ...)` element in the *root*, with no root uuid in front of it. And the
  root's own sheet entries take `(path "/")`.
- **Two label stubs on the same coordinate weld two nets together**, quietly.
  The first layout pass put +12V and VB_A on the same point. Cells are now sized
  from each symbol's own pin extent, and the emitter refuses to place a label
  where a different net already sits.

## Board S, one board

Board A and the minimum of board B on one Ø65 mm board, built as a
**variant of board A from the same generators** (decided 2026-09-22): the
three phase cells, the CPU wedge and the encoder are board A's, and the two
link wedges and the middle of the board carry the bus input, the bulk, the
TVS, both rails, USB-C, the RS-485 relay and an expansion header for a
stacked PD or Ethernet board. 48 V operational max. It lives in
`hardware/single_board/`; [single.html](single.html) is its page, with the
board viewer: schematic, copper and 3D.

```sh
python3 tools/placement_s.py            # the floorplan, img/board_s_*.svg, single.html's tables
python3 tools/schematic_s.py            # the netlist and its checks
python3 tools/gen_boards.py --board s --force   # emit, stitch, fan out -- destroys routing
python3 tools/route.py --board s --rounds 1     # freerouting, then the maze on what is left
python3 tools/route.py --board s --polish       # twice: the second pass reads the first's DRC
```

`gen_boards.py` with no `--board` still writes boards A and B only, and board
A's generated output is byte-for-byte what it was before board S existed --
checked by diffing the emitter's text, not by eye.

### Capture

`tools/schematic_s.py` builds the netlist out of `schematic.py`'s own
functions: the phase cells (clamps to the 54 V grade), `control()` with the
GPIO remapped, `encoder()`, the mechanical parts, and two new sheets,
`04_power` and `05_io`. 194 components, 111 nets, 585 pin connections (six bulk cans since 2026-09-28); ERC clean, and KiCad's exported netlist matches `schematic_s.nets()` connection for connection.
The bus comes in on an **XT30** (J4, since 2026-09-24; it was two arc pads, J4
and J5, for a pigtail): the rp2350-motor-controller's J9 -- the same
`Connector_Generic:Conn_01x02` symbol, the same KiCad footprint
(`AMASS_XT30PW-M_1x02_P2.50mm_Horizontal`), the same pinout, **pin 1 GND and
pin 2 VMOT**, and the same part, C431092 -- so one pack lead fits both boards.
The footprint is a project copy, `servodrive:`, written by
`gen_boards.xt30_body`: the same pads, holes, silk and model, with the
courtyard drawn round the housing, pins and peg ears instead of the library's
14.3 × 15.9 mm rectangle, whose empty corners are where two SM712s and a cap
sit. The placer checks the same outline, so KiCad's DRC and it agree.

Reading the LMR38010's datasheet (SNVSC73B) at capture changed three of the
sketch's values, all of which would have been wrong on the board:

- **VREF is 1.000 V.** The feedback bottom legs are 9.09k (12 V) and 24.9k
  (5 V), the datasheet's own table; the sketch's 11k and 27k made 10.1 V and
  4.7 V.
- **RT/SYNC may not float or be grounded.** Each buck has a 64.9k to ground
  now, 400 kHz; the sketch's modules had no RT resistor at all.
- **EN rises at 1.25 V (1.4 V max).** 470k over 22k would not have started
  the gate rail below 26 V. It is 470k over 68k: on at 9.9 V typically, 11.1 V
  worst case, off at 8.7 V -- inside the 12 V floor -- and it holds the
  2N7002's drain to 11 V when the TVS clamps at 87 V.

**The bucks' passives are TI's design points** (table 9-1 and sec. 9.2.2, 400
kHz from a 48 V bus), since 2026-09-23. The sketch's small parts -- 1 µF in,
a 3 × 3 33 µH inductor, one 22 µF 0805 out -- were well off them, and the
internal compensation is tuned for TI's L and C<sub>OUT</sub>: a 22 µF 0805 is
a few µF at 12 V. Now:

| | 12 V gate rail | 5 V logic rail |
|---|---|---|
| Inductor | 68 µH, SWPA4030S680MT (4 × 4, 0.72 A sat.) | 33 µH, SWPA4030S330MT (4 × 4, 1.1 A sat.) |
| Peak current at the spec's load | ~0.3 A at 0.1 A | ~0.7 A at 0.5 A |
| Output | 22 µF/25 V 1206 + 22 µF/25 V 1210 X7R, ~20 µF left at 12 V (TI: 22 nominal, 15 minimum) | 3 × 22 µF/25 V 0805 (TI: 3 nominal, 2 minimum) |
| Input | 100 nF/100 V 0805 at the pins + 4.7 µF/100 V 1206 X7S (TI: 4.7 µF minimum, 100–220 nF at the pins) | same |

L is the datasheet's equation 10 with the ripple taken on the part's 1 A, as
TI says to for light loads; both are well above the subharmonic minimum and
give 0.2–0.35 A of ripple, above the 10 % current mode needs. The effective
capacitances are estimates from typical DC-bias curves; the maker's figures
were not to be had.

**GATE_EN is GATE_OFF on board S.** The 12 V buck's EN sits on a divider from
the bus, up to 8 V, which no GPIO may see, so the 2N7002 the sketch proposed
does the pulling -- and that inverts the GPIO's sense: GPIO2 *high* kills the
gate rail. The net is named for what high does. Through a reset the pin is
pulled down (4k7, against RP2350-E9, like the drivers' pulls), the FET is off,
the rail is on and the low sides brake -- which is what spec §3 asks of a
reset. Firmware writes 1 to kill instead of 0.

Two symbols the stock library does not have: the **LMR38010**, drawn from the
datasheet's pin table (1 GND, 2 EN, 3 VIN, 4 RT/SYNC, 5 FB, 6 PG, 7 BOOT,
8 SW, EP) because the LMR336x0/LMR36510 that share its package do not share
its pins; and the **SIT3088**, derived from the MAX3485 as the sister project
wires it, so the library and the sheet hold the same flattened symbol and ERC
has no stock `extends` to compare against.

### Layout

`placement_s.layout()` is the sketch's search frozen by one set of options
(`LAYOUT`). Building a real board from it found what a courtyard sketch cannot:

- **A through-hole lead is copper on both faces, at 60 V.** The sketch tested
  the cans' leads as circles of half a pad side plus 0.2 mm, and C1001's +
  lead -- a 2 mm square pad, 1.41 mm on its diagonal -- landed on U15's pin 7
  on the other face. Leads are now their pads' bounding circles plus 0.45 mm.
- **The sister project's DFN-8 courtyard is smaller than its pads** (±1.6
  against ±1.72): two SIT3088 sat 0.05 mm pad to pad with their courtyards
  apart. Widened for placing.
- **60 V parts keep 0.25 mm more** from their neighbours: the EN divider's
  top resistor had its VBUS pad 0.36 mm from two ground pads.
- **The buck module was drawn before the pinout was read.** It had its input
  cap by RT and its divider on the input side. It is now laid against the
  pins, TI's own example layout (fig. 9-16): the input cap left of pins 1–3,
  RT under pin 4, the divider at pin 5, the bootstrap cap at 7–8, the
  inductor over the switch corner. EN is between GND and VIN, and on board S
  it leaves as a 0.15 mm track between the input cap's pads -- 0.40 mm from the
  VIN one, if the cap sits 0.03 mm low -- to the divider beside it. On the
  back the module is mirrored, as its footprints are, and it turns in 15°
  steps; with the divider in it, it fitted nowhere rigid, and it places with
  1.2 mm of give per part.
- **TI's parts do not fit a rigid module.** The signal wedge held the small
  one with fractions of a millimetre to spare; a 4 × 4 inductor alone, or the
  4.7 µF alone, left both bucks nowhere. So `put_module` now keeps rigid only
  what has to be on a pin (the 100 nF, bootstrap, RT, feedback divider and EN
  divider) and places **satellites** after them -- the inductor with its SW
  pad within 4.5 mm of pin 8, the first output cap by the inductor's output --
  each at the nearest legal spot, square to the module. The rest are **near
  parts**, placed last, anywhere on either face that puts them on their copper,
  so the USB front end keeps the room it needs by the connector. Three still
  had none in the link wedges -- both 4.7 µF caps and the 12 V rail's second
  22 µF -- and go in the **outward centre** (decided 2026-09-23): ceramics,
  nothing switching or ferrous, and never in front of the CPU: between the
  M3 head at (0, -9.5) and C1002 is the outward face's one way from the
  RP2350 to the header, encoder and LED, and the 12 V cap there left five of
  them unrouted. The 4.7 µF caps are 10–18 mm from their bucks, beside phase
  A's DC-link caps; across the In1/In2 plane pair that is a
  nanohenry or two, nothing at 400 kHz, and the 100 nF at each IC's pins takes
  the edges. The EN divider may slide along its channel from pin 2, not across
  it: flexed a millimetre across, its VBUS pad sat in the EN track's way.
- **The bucks must not stack.** The 12 V module on the signal wedge's back
  over the 5 V one on its front left the divider's VBUS pad with nowhere to put
  a via on either face.
- **The cans' + leads point outward**, onto In2's VBUS at R 17, the short way
  to the bridges.
- **The RS-485 relay is placed for its wiring.** Port IN takes the rim slot at
  241° beside its two transceivers and OUT the one at 219° beside its own (the
  sketch had each port's pairs crossing the other's); every SIT3088 is turned
  so its A/B pins face its port, its 100 n goes past the end of its pin row and
  its 120 Ω beyond its escape vias. The four chips fill the quadrant of the
  motor-facing centre between the two M3 standoffs, C1001's leads and the
  magnet keepout; with the ports the other way round the fourth has no room.

### The XT30

Added 2026-09-24 (asked for as "add xt30 for power, look at my rp2350 motor
controller as a reference"): an AMASS **XT30PW-M**, horizontal, on the power
wedge's axis on the outward face, mouth outward, in place of the two bus pads.
It took three goes to find where, and the answer moved more of the board than
the connector:

- **A horizontal XT30 cannot sit at the edge.** Its two locating pegs, 11 mm
  apart and 3.6 mm behind the mouth, are through-holes, and at the rim they
  land on the motor-facing face exactly where the two RS-485 ports are. No
  other stretch of rim on the board takes a JST SH: the CPU wedge's is the
  RP2350's escape-via field, which goes through both faces, and the signal
  wedge's is 0.1 mm short beside the USB-C, on either face. A flush XT30
  would have cost one port and the relay with it.
- **So it sits back** (decided 2026-09-24, "horizontal set back ~5 mm"): its
  face is at R 27.5, 5.0 mm in from the edge, the nearest its pegs come to
  clearing the ports. The plug's first 5 mm lie over the board, and
  `placement_s.PLUG` keeps that path clear on the outward face. Its pins land
  at R 14.5, inside the centre -- `placement_s.place_xt30`.
- **It is placed by its body.** The library courtyard is a 14.3 mm rectangle
  to take the peg ears, which spends 3 mm either side of the pins at the back
  -- the room the TVS needed. The placer uses the housing and pins (10.6 mm)
  and keeps each ear as a circle on the same face; a peg (no net) keeps its
  drill out of the far face's courtyards and its ring 0.25 mm from their
  copper (`PEG_FPS`), not the 60 V leads' 0.45 mm.
- **C1001 moved to 135°**, across the M3 head at 180°, in front of phases B
  and C: the power wedge's quadrant of the centre is the XT30's back end.
- **The SMDJ54A is under the XT30** on the motor-facing face, between its pins
  and its pegs, cathode toward the VMOT pin -- the one place left on the board
  for an SMC, and it had to go in before the ESD parts and the bucks or they
  took it. The four SM712s are two stacks, one each side outside the pegs: the
  DOWN pair's on the ports' face, the UP pair's over it on the outward face.
- **The motor-facing centre is full.** The XT30's pins and the TVS take one
  quadrant and the cans' leads split two more; what is left holds one tidy
  pair of SIT3088s. They were also asked to be tidier (2026-09-24, "make the
  SIT placement cosmetically cleaner"): all four are now turned alike, square
  to the board with their bus pins toward the ports, each with its 100 n past
  pin 8 and a receiver's 120 R past its A/B pins in the same place -- the OUT
  pair side by side in the upper right, U14 and U15 alone where they fit
  (`Sketch.put_rigid`, `Sketch.pair`); later parts keep out of the strip in
  front of each pin row where the fan-out puts its escape vias
  (`ESC_KEEP`), and a transceiver's escapes keep out from under the VBUS
  spine on the other face -- loosely placed, the divider first sat on U15's,
  then the spine did. "Place the rest loosely" (decided the same day) put the
  **bus divider in the motor-facing centre**, one row between the XT30's pins
  and the magnet, which the 2026-09-22 rule kept out -- with the XT30's pins
  in there it no longer buys anything; R801's VBUS pad gets a finger of In2
  as the centre caps do. **BOOTSEL** is at the top of the outward centre, its
  one spot; the 3V3 LDO in the upper right with its two caps; the 12 V rail's
  second 22 µF on the power wedge's front beside the XT30. `placement_s.SPINE`
  keeps the VBUS spine's path clear of parts.

`gen_boards.py --board s` adds three pieces of copper board A never needed:

- **In2** is VBUS everywhere but the CPU wedge (306° round through 0 to
  254°) and +3V3 over the CPU wedge and the centre disc, with a tab reaching
  in over each can's + lead and over the XT30's VMOT pin (R 14.5, inside the
  disc; 3.4 mm deep and ±10°, the whole bus comes in there), and a finger in
  under each centre VBUS pad (the 4.7 µF caps', R801's): VBUS is plane-only,
  never routed, so that is its way in. Board A's signal-wedge ground on In2 went: the
  bucks are there now, and they want the bus.
- **The VBUS spine** on the outward face: the XT30's VMOT pin and the
  expansion header's four VMOT pins as one piece of copper, with a 3.4 mm disc
  round the pin. The header is on the axis, inside In2's +3V3 disc, and a PD
  board can put 5 A through it; this is its way to the bus. (With the bus
  pads it also took in the TVS's cathode and C1001's + lead.)
- **A field of barrels round each XT30 pin** (`fanout.pin_field`): the pins
  are plated holes and join every plane they pass, but the whole bus goes in
  at one pin and In2 is 1 oz, so the spine gets its own ways down to In2's
  tab -- 10 vias round the VMOT pin, inside both -- and the ground pin 7 into
  In1 and In4, none of them through the VBUS tab. (The bus pads had theirs
  from `fanout.bus_field`, which is still there for a board with pads.)
- **Fences over In2's VBUS fingers** (`gen_boards.fence_fingers`, after the
  fan-out): a rule area on In2 that allows no vias, from just past each
  finger's pad to 1 mm into the VBUS annulus, cut round any via already there.
  A finger is 2.6 mm wide, two of the router's vias side by side cut it, and
  the fill then drops its end as an island: the first route with the XT30 left
  C1007 off the bus that way. KiCad's DSN export makes each one a
  `via_keepout` for freerouting, and `finish.py` now keeps a via out of any
  rule area that allows none, whatever layer it is on.

The fan-out gained two passes and eight escapes: `near_links` lays each buck
module's own connections -- VIN to the input cap, the switch node through the
bootstrap cap to the inductor, BOOT, FB, RT, the output, pin 1 to the input
cap's ground -- as locked copper, since a module turned in 15° steps is off the
grid freerouting needs; `pin_field` above; and the USB-C, the two SH 6 ports,
the USB ESD part and the four SIT3088 get an escape via per pad, as the flash
and the INA241s do. The SIT3088s were found the hard way: 0.28 mm pads at
0.65 mm, and on the first four routes the router reached pins 1, 4, 6 and 7 of
none of them, which is the INA241's trap from board A again. Plane taps now do
supply pins before ground -- a ground tap laid first crossed the only way from
a transceiver's VCC pin to its capacitor -- and a pad that cannot reach its
plane is joined to a neighbour of its net that did.

**Three bugs in the tools, found here and not on board A:**
`fanout.legal` held a 60 V track only 0.15 mm from ordinary copper -- the wide
clearance applied when the *obstacle* was a 60 V net, never when the new copper
was, and board A's tools never laid 60 V copper -- and neither it nor
`stitch.py` knew that a footprint can ask for more than its netclass (TI's
PowerPAD footprint carries 0.2 mm). And **the Specctra session rounds every
part's rotation to a whole degree** -- the DSN says Q1 is at -68.403°, the session
says 292 -- and KiCad's import turns the parts to match: on the routed board A
today 93 of 140 footprints sit up to 0.48° off the generator's angles (the FETs
0.40°). Board A is DRC-clean as it stands and was not touched; `route.import_ses`
now puts every part back, so it straightens the next time it is routed. On
board S it was a USB-C pad moved 0.024 mm onto the fan-out's stub beside it.

### The bulk: six small cans

Changed 2026-09-28 (asked for as "we should fix the caps, try several
options", then "go with 6x6.3"); [bulk.html](bulk.html) has the options and
the numbers. The board's first bulk was two Ø10 cans, 100 µF/100 V polymer
(C2887236, 2.5 A of ripple at 100 kHz). The simulation's DC-link network put
6.4 A RMS through each at the design point, and every candidate datasheet that
gives a frequency table takes 0.7 of the 100 kHz rating at 10–100 kHz, where
this ripple lives: 3.7 times the rating, 1.4 W in each can, good for about
5.5 A RMS per phase continuously.

- **At 20–40 kHz cans in parallel share by capacitance**, so a bank carries
  what the ripple rating per microfarad of its part allows. A Ø10 100 µF part
  is rated 2.5–3.2 A; a Ø6.3 × 9 22 µF part 2.6 A, four times as much per µF.
  Mixed banks lose: a Ø10 among small cans takes 5 A on its own. Ceramics
  cannot take a useful share (twenty 10 µF 1210s are 70 µF at 48 V), and a
  better Ø10 in the same footprint gets to 7 A.
- **What fits is three pockets.** Every spot on the outward face was tested with
  `placement_s.legal()` against the parts that cannot move: the outward centre
  has a pocket between each pair of M3 heads at 45, 135 and 315°, each taking
  one Ø10 or Ø8 or two Ø6.3 (phase A's driver keeps a Ø10 out of the 45° one).
- **Six Ø6.3, jieerrui PA100V22M6X9** (C49233038, 22 µF, 30 mΩ, 2.6 A at
  105 °C and 100 kHz; Shengyang's SH226M100E0900 is the same part on paper):
  132 µF, 2.3 A per can against 1.8 A at 20–40 kHz, 0.16 W each, within
  rating to 15–16 A RMS per phase continuously. They stand 9.5 mm, not 13.
  The price is the capacitance: bus ripple rises from 1.75 to 2.43 V
  peak-to-peak (2.55 at the worst corner, against 3 V), and the battery lead
  carries 3.2 A RMS of ripple on 1 µH instead of 2.0. The whole simulation,
  re-run on the routed board, agrees: 2.26 A per can, within rating to 16.1 A
  per phase, and the planes from the cans to a cell 1.1 nH (2.9 with two).
- `schematic_s.BULK_KIND` picks the bank (`BULK_VARIANTS`: 2 × Ø10, 3 × Ø8,
  5 or 6 × Ø6.3) and `placement_s.BULK_SITES` where each can goes; the sheet,
  the In2 fingers (`gen_boards.in2_s`) and the simulation (`sim/lib/board.py`)
  follow the netlist. With the old bank selected the placement is part for part
  what it was.
- **Swapped into the board as built, not placed first.** With the six cans
  put down first and everything after them, some sixty parts moved -- the
  buck modules by 0.4 mm round C1002's new lead, and the overflow caps, the
  LED and the relay after them -- and the board stopped routing: six
  connections left at best, after targeted rip-ups. So `placement_s._swap_bulk`
  builds the board with its two Ø10 cans, as it was routed, takes them out,
  puts the six in at `BULK_SITES` -- the spots and turns that displace fewest
  parts, found by trying every legal spot in each pocket against the board --
  and places again only what they land on, each at the nearest legal spot to
  where it was: 16 parts of 182, most by 0.2–4 mm. Transceivers stay inside
  R 17.5; out in the ring one sat among phase A's sense parts with its input
  pin cut off from the CPU.
- **What moved.** The LED went beside the header, (-8, 5.5), with its
  resistors. Port IN's receiver U14 lost its spot to C1015 and went to the
  top of the motor-facing centre (-4.5, 13.5); port OUT's driver U17 took the
  spot below the header at (6, -5) that U14 had had, near enough. U15, U9 and
  C713 moved a few millimetres; SW1, the VBUS-detect divider and the LDO row
  a fraction of one.

### Routing

The board is routed by the same pipeline as board A: `route.py --board s
--rounds 1` hands what the tools did not make to freerouting, one strict
round, and the maze (`finish.py`) takes what comes back in pieces.
**1913 track segments and 411 vias, every one of the 577 pin
connections made, DRC clean** (no errors, no warnings), nothing but ground
under the heatsink land, no right-angle corners. 313 of the vias are the tools'.
(Before the XT30: 1804 segments and 405 vias, made with `--first
EN_12V,USB_VBUS,LIN_A,EXP_GP19`, the maze making those four nets before the
router.)

It took more than board A did, and what it took is worth keeping:

- **Freerouting is deterministic for a given board.** Four identical runs gave
  four identical results; what changed the outcome between runs was always a
  change to the board. So the tail is attacked by changing the board, and
  variants are run side by side in scratch copies with `route.py --pcb COPY`
  (and `--first NETS` to have the maze make some nets before the router).
- **The last nets were placement, not routing.** The RS-485 pairs were the
  leftovers until the transceivers got escapes; EN_12V until the 2N7002 sat
  beside the divider it pulls; the expansion header's GPIO until its signal
  pads got escapes too -- its north row faces away from the CPU.
- **`route.py` now saves atomically.** pcbnew once segfaulted inside
  `SaveBoard` after a long maze pass and left a 0-byte board; the board is
  written to a temporary name and renamed over.
- `--loose-first` makes the first round loose, for a board that is already
  routed; like the loose rounds on board A, it did not close the last two
  here.
- **With TI's buck parts (2026-09-23) the plain run ends five short**, all of
  them the RP2350's way into the centre -- the header's GPIO, the encoder's
  clock, the LED, FET_TEMP -- and a second strict round changes nothing, a
  loose one runs out the hour. Two things closed it: the 12 V rail's overflow
  cap had landed in the one gap on the outward face between the M3 head at
  (0, -9.5) and C1002, and the centre's overflow now keeps out of the CPU's
  sector; and the maze makes EN_12V, USB_VBUS, LIN_A and EXP_GP19 before the
  router, which with the 2N7002 15 mm from its divider (no room beside it on
  the module's face now) is what leaves the router a board it can finish.
- **With the XT30 (2026-09-24) the plain round is the one that finished.**
  Four variants side by side; freerouting left two connections for the maze
  with the old four nets made first (FET_TEMP, USB_DP), seven with LED_R, LED_G
  and FET_TEMP added, sixteen with only LED_R and FET_TEMP, and seven with no
  maze first at all -- and the maze made all seven of those, so the others
  were stopped there, unfinished. The first plain route had
  also left C1007 off the bus: its VBUS reaches In2 through a 2.6 mm finger,
  and two of the router's vias side by side cut it -- hence the fences
  (`gen_boards.fence_fingers`). One route died in pcbnew without a word
  after freerouting, as a save once did; the atomic save is why that costs
  nothing.
- **`spread_holes` could not see a router's via** at 146.6926 mm, which the DRC
  report gives as 146.693: it matches the nearest hole now, and when the
  offending via is boxed in it moves the other one of the pair, a little off
  straight-apart if it has to (here the header's +5V escape via, 35 µm).

- **With six bulk cans (2026-09-28/29) it took the maze first and three
  rip-ups.** Twelve can leads in the centre, and C1015's VBUS finger with its
  no-via fence, stand in the corridor from the RP2350 into the centre; the
  best plain and `--first` routes stopped one to five short, always there
  (EXP_GP24, XIN and RS485_OUT_TX took turns being the last). What closed it:
  the maze making the RS-485 IN pair and the encoder's CS and DO before the
  router as well, three left, and a targeted rip-up each for EXP_GP24, HIN_A
  and SWCLK -- rip exactly the nets on the cheapest way through, make the open
  net, make them again, keep it only if nothing opens.

**How the board on disk was made, exactly** (2026-09-29): from the generators
as committed, `gen_boards.py --board s --force` (with `BULK_KIND = "6x6.3"`),
then in a scratch copy `route.py --board s --rounds 1 --first
EN_12V,USB_VBUS,LIN_A,EXP_GP19,EXP_GP22,RS485_IN_DN_N,RS485_IN_DN_P,ENC_CS,ENC_DO
--pcb COPY`, `--polish` twice, three targeted rip-ups (EXP_GP24, HIN_A,
SWCLK), copied back, `--polish` twice more, and two escape vias left dangling
(HIN_A, RUN) and the stub one left removed. 2241 segments, 444 vias, 359 of
them the tools'. DRC (all severities) is clean; schematic parity reports the
same 219 items as the board before, of the same kinds -- hierarchical net
names against the board's flat ones, and the mechanical lands' values; ERC,
the netlist diff and deadcheck all pass. The boards before this one are in
git: two Ø10 cans (b348b20), the bus pads (8f9342f).

### Not checked

- **The bucks' loops, on the bench.** The passives are TI's table-9-1 values now (see Capture), but the effective output capacitance at bias is an estimate, and TI asks for a load-transient test or Bode plot before production. Neither inductor is rated to the LMR38010's 1.9 A high-side limit, which TI calls ideal: a hard short on either rail saturates it until hiccup mode stops the part.
- **The motor-facing centre.** Heights are package maxima, not chosen parts; whatever is bought has to stay under 1.5 mm. Some SOT and DFN lead frames are Alloy 42, which is magnetic; at 7–16 mm from the sensor it should not matter, and the encoder's field budget has not been re-run to prove it.
- **Copper under the standoffs.** On the motor-facing face a few tracks and a via sit inside the M3 standoffs' 3.25 mm circles — on board A as well, where `route.py` keeps copper only from under the screw heads on the outward face. Under solder mask, and not yet a rule.
- **The XT30's rating.** AMASS rates the XT30 for 15 A continuous (the LCSC listing says the same); the design point's DC link is 17 A in a burst. Fine for bursts, not a continuous-duty connector at full power.
- **The plug over the board.** The XT30's mouth is 5 mm in from the edge, so the mating plug's first 5 mm lie over the outward face. The path is kept clear of parts, not of silkscreen or anything clamped to the board.
- **The XT30's 3D model** is the SolidWorks STEP the rp2040/rp2350 motor controllers use (`hardware/parts/3dmodels/XT30PW-M.STEP`); its licence is not recorded there, and this repo is public.
- **Height.** The cans are 9.5 mm tall on the outward face (six Ø6.3 since 2026-09-28; the two Ø10 were 12–13 mm). A stacked expansion board on the 4.3 mm socket sits about 6 mm up and needs holes over them.
- **The heatsink ring.** Board A clamps an aluminium ring on the phase cells' lands. The USB-C reaches the edge in the signal wedge, so a continuous ring would need a gap there.
- **VMOT through the header.** A PD board feeding the bus puts up to 5 A through the header, whose end pins are about 6 mm from the encoder. With VMOT and GND pins paired it passes as a dipole, roughly 0.1 mT against the magnet's 20–100 — estimated, not simulated.
- **The cans at temperature.** The six cans are within their ripple rating to 15–16 A RMS per phase (see [The bulk](#the-bulk-six-small-cans)); above that, 20 A is a burst. Their ratings are the datasheet's at 105 °C, and the datasheet gives no multiplier for a cooler board, so how long a 20 A burst may last is for a thermocouple on a can to say.
- **RS-485 fail-safe.** Every receiver has a permanent 120 Ω and no bias network; an idle or open link relies on the SIT3088's own fail-safe, which the datasheet has to be shown to give with the termination present (the sister project's F-01).
- **The RGB LED's pinout.** `LED_RGB_1210` with a common anode on pad 4 is an assumption: 1210 RGB parts differ. Check against the part bought.
- **Firmware.** GPIO2 is `GATE_OFF`, active high, and GPIO3 `FAULT_n`; UART0 on GPIO0/1 is port IN and a PIO UART on 14/15 port OUT; the encoder is on SPI0 (ENC_DO GPIO4, ENC_SCK GPIO6); USB_VBUS_DET is GPIO25; 19–24 go to the expansion header.
- **Stock.** The XT30, C431092, had 68,987 at JLCPCB (2026-09-24). The bucks' parts are checked at JLCPCB (2026-09-23): LMR38010SDDAR C5219310, SWPA4030S680MT C83473, SWPA4030S330MT C83470, 4.7 µF/100 V 1206 C237304, 100 nF/100 V 0805 C28233, 22 µF/25 V 1206 C12891, 1210 C21397, 0805 C45783; C2887236 is stocked. SMDJ54A, TPSMF4L54A, SIT3088 and SM712 are not checked yet.

## Licence

CERN-OHL-P, like its parent. Design by Sequoia Hope Alexander.

## Power sources

VMOT accepts a 12–60 V battery on XT30 **or** a USB-PD contract, ORed by an
LTC4359 ideal diode. The 12 V gate rail's buck cannot boost, which gives three
clean states:

| Source | VMOT | Gate rail | Drive can |
|---|---|---|---|
| USB, no contract | 5 V | down | configure, read the encoder — not energise a phase |
| USB-PD, 12–20 V | 12–20 V | up | run, capped at 100 W by PD |
| XT30 battery | 12–60 V | up | run; full performance at 60 V |

At a 12 V bus the gate rail's buck is at its 97 % maximum duty and the rail
sits near 11.5 V — above EG2103's 9.7 V turn-on, which is why 12 V is the floor.
The rail's enable is pulled **on** and `GATE_EN` can only pull it off, because
a reset is meant to brake and a brake needs the gate rail.

PD **replaces** a pack; the two are not used together. With VMOT down to
12 V a 20 V contract could otherwise back-drive a lower-voltage pack, so that
is an operating rule rather than a circuit: the PD path stays one LTC4359 and
one FET, which keeps VMOT out of the USB host, and a USB cable for
configuration with a pack on the XT30 is still safe because PD without a
contract is 5 V. Firmware should ask for more than 5 V only when the bus reads
what USB alone would give it. The XT30 stays a straight pass-through, so regen
still reaches a pack.

## Sourcing

Stock figures below were checked 2026-09-07 and **rot**. Re-check before ordering —
the sister project's F-40 is a board that cannot be built because one part has nine
in stock.

| Part | LCSC | Stock | MOQ | @100 | Note |
|---|---|---|---|---|---|
| EG2103 | C480654 | 2,225 | 5 | $0.19 | **chosen** — 600 V, VCC 10–20 V, interlock + 560 ns dead time, ±0.3/0.6 A |
| NCP5183DR2G | C904511 | 2,883 | 1 | $0.92 | alternative: 4.3 A, but no interlock or dead time |
| UCC27282DR | C2867844 | 1,227 | 1 | $1.99 | alternative: ±3 A, VDD 5.5–16 V |
| EG2131 | C193777 | — | — | — | **not available** |
| FD2103S | C5187182 | — | 5 | $0.10 | **out of stock** |
| BSC030N08NS5 | C501507 | 27,306 | 1 | $0.60 | inherited, unchanged |

**Every placed part has an LCSC number since 2026-09-24**, in
`hardware/parts/lcsc.csv`: one row per value and footprint, each checked against
JLCPCB's library that day (model, package, rating, stock), with a note where the
choice was not obvious; the viewer's build lists any placed part without one,
and the 3D viewer's part pane links each to LCSC and JLCPCB. Two values changed
to reach a stocked part: the shunts (2 × 2 mΩ, see Current sensing) and the
flash (**W25Q16JVUXIQ**, 16 Mbit, the RP2350 reference design's part — no 128
Mbit flash comes in the footprint's USON 2×3). Watch before ordering: TPSMF4L64A
(60 in stock) and TPSMF4L54A (42), the 2×14 1.27 mm SMD header (50, the only
one); the RGB LED is a 3528 part placed rotated 180° (its pads 1–4 are B, A, G,
R); the RS-485 connectors are an SH-compatible part whose land pattern wants a
check against the footprint.

Still unverified, and now more urgent because the layout depends on their packages:

- **INA241A3** — `INA241A3IDDFR`, **TSOT-23-8**, 50 V/V. Not A2 (20 V/V) and not
  SOT-23-8; draft 0.2 had both wrong. In stock as C6051860 (2026-09-24). `INA240A2PWR`
  (C129949) is in stock as a fallback, but it is TSSOP-8 and only ±80 V common
  mode against INA241's ±110 V — a different footprint and less margin on a 60 V
  phase node.
- ~~**1.6 mΩ 2010** shunts at 1%~~ — none is stocked; 2 × 2 mΩ since 2026-09-24, see above.
- **3.3 µH inductor** for the RP2350A's core buck, and the rest of the CPU
  support parts capture turned up.
- **TPSMF4L64A**, **LMR38010**.
- **Bulk capacitance on board B is no longer a catalogue item.** See spec §8:
  ~9 A RMS of ripple at 20 kHz reaches it, and three ordinary 100 µF/100 V
  electrolytics are not rated for that.

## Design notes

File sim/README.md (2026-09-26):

# sim/ — the servodrive electromagnetic simulation

`SPEC.md` is the brief. This is what was built from it.

```
sim/
  SPEC.md          the brief
  FINDINGS.md      the register: every finding, its evidence and its disposition
  HANDBACK.md      the constants to change, the firmware to change, and why
  run.py           reproduces everything:  python3 sim/run.py
  setup.py         builds the solvers this machine does not have
  report/          the report; served by `proj up servodrive`, at /sim/report/
  results/         P0.json … P9.json — the only thing the report reads

  extract/         board -> work/geometry.json, and the pictures to check it by
  lib/             paths, result IO
  models/          one JSON per part: the value, the source, the date read
  fasthenry/       PEEC: the runner, the mesher, and the cell-A models
  fastcap/         the electrostatic runner
  spice/           libngspice binding, the fitted devices, the cell netlist
  conduction/      the L5 finite-difference solver and its rasteriser
  loop/            the L4 system: motor, inverter, SimpleFOC's own control law
  encoder/         L6: the field at the MT6701
  field/           L2: openEMS, in a container
  thermal/         L7, the optional phase
  phases/          one module per phase, each returning the JSON it writes
  tests/           the known-answer tests of SPEC.md §5.4
  work/            regenerable: board copy, geometry, solver scratch
```

## Running it

```sh
python3 sim/setup.py          # build FastHenry2, FastCap2, the openEMS image
python3 sim/run.py            # every phase, in order
python3 sim/run.py --phase P2 # one phase
python3 sim/run.py --list     # what is done
python3 sim/run.py --board s  # board S: results/s/, report/img/s/, work/s/
python3 sim/tests/kat.py      # just the known-answer tests
proj up servodrive && proj url servodrive     # then /sim/report/
```

## Board S

`--board s` runs the same phases on `hardware/single_board/servodrive_S.kicad_pcb`.
Its results go to `results/s/`, its figures to `report/img/s/` and its scratch to
`work/s/`, so board A's numbers are never overwritten. What differs is in
`lib/board.py`, the one place a phase asks for a design constant: a 48 V bus
(the envelope 20/48/56 V, 56 V being the top of the firmware fold-back), the 54 V
clamps (Q2's criterion becomes 57 V, board A's 3 V under the clamp's minimum
breakdown), the 2 × 2 mΩ shunts at 50 mV/A, the Ø6 magnet at a 1.5 mm gap, and a
bulk that is two polymer cans on the board itself: P1 solves the plane path from
the cans to cell A in place of the header, and P4 becomes the cans' ripple current
against their rating, with the battery lead on the far side. P5S is board S's own
encoder check; P9 is `phases/p9s_summary.py`, which grades each question and writes
the simulation section of `single.html` between `<!-- sim:begin -->` and
`<!-- sim:end -->`. `tools/route.py` starts this run (detached, through
`tools/regen.py`) whenever it finishes routing board S with nothing unconnected.

`--quick` coarsens every sweep. It is for developing the code, never for a
result: the report does not record which mode produced a number, so do not mix
them.

## The solvers, and why they are where they are

There is no passwordless `sudo` on this machine, so nothing is apt-installed.

| Level | Solver | How it got here |
|---|---|---|
| L1 | FastHenry2 3.0.1, FastCap 2.0 | built from the FastFieldSolvers sources into `~/opt` by `setup.py`, with the patches a 2026 compiler needs |
| L2 | openEMS | built inside a container; only `sim/` is mounted |
| L3 | ngspice | through `libngspice.so.0`, which KiCad installs — there is no CLI here |
| L4 | own code | `loop/`, with SimpleFOC's PID and low-pass reimplemented line for line |
| L5 | own code | `conduction/`, a coverage-weighted finite-difference Laplacian solved with pyamg |
| L6 | magpylib | pip |
| L7 | own code | `thermal/`, the same Laplacian with k instead of sigma |

Every one is checked against a closed form before it is used; the checks are in
`tests/kat.py` and their results are in `results/P0.json`.

## Rules this code obeys

- It never edits `hardware/`. The board is copied into `work/` before anything
  that could write it, and nothing here runs `gen_boards.py`.
- Every component value in `models/*.json` carries its source and the date it
  was read. A value that could not be found is marked `bracketed` and swept,
  never quietly replaced with a typical.
- `results/*.json` is the only thing the report reads, so a re-run cannot put
  yesterday's number beside today's figure.
- A solver that will not converge is a finding, not a gap: see S-21 and the
  Q11 section of the report. The corollary bit harder than the rule: a solver
  that *looks* converged is not one either. Both solvers answered Q1 on a mesh
  neither had been refined past, from opposite sides, and the disagreement was
  read as a solver difference until each was swept.
- A mesh is snapped to the copper, not laid over it. In FDTD there are no
  nets, only metal: two conductors within one cell of each other are one
  conductor, and this board's tightest clearance is 0.40 mm. A uniform mesh
  coarser than that joins VBUS to GND and returns a commutation loop half its
  size, without warning and without failing any check the run makes on itself.
  `field/geom_export.fixed_lines()` pins a line to every polygon vertex and
  every barrel wall, and `field/cell_scripts` merges every line through one
  minimum spacing — including the port's own edges, because one stray
  near-duplicate put the timestep at 2e-17 s and the run never finished.
- A warning is read before it is believed. openEMS reported 127 "unused
  primitives" in the first cell-A model and they were recorded as lost copper;
  they were via pads lying inside the barrel cylinders that already provide
  that copper at a higher priority. `geom_export.drop_barrel_shadowed()`
  removes them so the warning means what it appears to mean.
- A device is modelled where its terminals actually are. The MOSFET's
  `R_g(int)` is a real resistor between the package pin and the polysilicon
  gate, and `C_gd` and `C_gs` meet behind it, because that is what decides
  whether the channel conducts; hanging `C_gd` on the pin instead inflates the
  induced `V_gs` of Q4 several-fold. The gate driver's output stage is a
  resistance to its rail with the body diodes of its own output MOSFETs across
  it, not a current limit, because external current pushed into the pin has to
  raise it rather than vanish.
- Where a datasheet gives a number without its test condition, the reading is
  bracketed and the bracket is swept. The EG2103's output impedance is the
  largest such bracket in the report and sets the edge rate; see Q2.

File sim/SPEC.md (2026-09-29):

# servodrive — electromagnetic simulation specification

**For:** the agent that will build and run the simulation (Opus).
**Written:** 2026-09-11, from board A as routed on 2026-09-09 (130 parts, 84 nets,
413 connections, DRC and ERC clean) and from the sibling project
`~/pcb/rp2350-motor-controller` (firmware, tuner, findings register).
**Owner:** Sequoia Hope Alexander. Licence of everything produced: CERN-OHL-P, like the board.

---

## 0. Read this first

### 0.1 What this is

A plan for a comprehensive electromagnetic simulation of the servodrive motor board
(board A) and of its power link to board B, with the drive's firmware and its motor
modelled well enough that every electromagnetic result lands on a decision about the
board, the firmware, or the enclosure. It is not a research project. Every phase ends in a
number, a figure, a pass/fail against a stated criterion, and a hand-back.

The board has been designed on closed-form estimates that live in `tools/geometry.py`
(loop inductance, ripple split, loss budget, sense full scale). The simulation's job is to
replace each of those with a solved number, say by how much the estimate was wrong, and
say what changes if it matters. Appendix A lists the estimates and their arithmetic.

### 0.2 What "done" means

1. `sim/` exists in this project and `python3 sim/run.py` reproduces everything —
   results JSON, figures, report — from the board file and the constants, on this
   machine, with no hand steps.
2. Every question in §4 has an answer in `sim/results/<phase>.json` with a figure, the
   method, the validation test that passed for the solver used, the convergence
   evidence, and a disposition in `sim/FINDINGS.md` (register format in §8.3).
3. A static report `sim/report/index.html`, linked from the project's `index.html`,
   viewed through `proj up servodrive` and `proj url servodrive`.
4. A hand-back list (§8.4): exact constants to move in `tools/geometry.py`,
   `tools/placement.py`, `tools/fanout.py`, plus firmware recommendations, each tied to a
   result.

### 0.3 Ground rules — not negotiable

- **No claude.ai Artifacts.** Reports are static files in the project, served the
  registered way. Never start an ad-hoc HTTP server; never hardcode a port. The project is
  already registered with `proj` (`~/scripts/launcher.toml`, entry `servodrive`). The port
  comes from `--port`, then `$PORT`, then `proj port`, then fail loudly.
- **Never edit `hardware/` by hand and never run `python3 tools/gen_boards.py --force`**
  — it throws away the routing. The board is generated: any change the simulation wants is
  proposed as an edit to a constant in `tools/*.py` (hand-back list), never as an edit to
  the `.kicad_pcb`. `hardware/` is not under git. Copy the board into `sim/work/` before
  anything that writes it (zone refills, pcbnew scripts that save).
- **The RP2350 regulator cluster and the 1V1 ring follow Raspberry Pi's RP-006440
  reference** and are not up for change.
- Never `pkill -f` a pattern that appears anywhere in your own command line (it has killed
  the shell four times on this project).
- **Cite every component value.** Datasheet numbers go in `sim/models/<part>.json` with the
  source URL and the date read. If a value cannot be found, say so and bracket it; never
  silently pick a typical.
- **Every solver gets a known-answer test before it is believed** (§5.4). Convergence in
  mesh, grid, or time step is reported with numbers, not assumed.
- **Report faithfully.** A failed toolchain build, a solver that will not converge, a
  criterion that is not met: all of these are findings, written down as such.
- The motor is deliberately undefined in the design (spec §11, question 1). Do not pick
  one. Model it as a parameter set and sweep it (§3).

---

## 1. The design under simulation

### 1.1 Source of truth

| What | Where |
|---|---|
| Board A layout, routed, zones filled (138 filled polygons in the file) | `hardware/motor_board/servodrive_A.kicad_pcb` — KiCad 9, 2.9 MB |
| Board A schematic (generated; four sheets) | `hardware/motor_board/*.kicad_sch` |
| Every dimension, the design point, the analytic model | `tools/geometry.py` — `python3 tools/geometry.py` prints the model (it also regenerates `img/*.svg`) |
| Every part position, polar, and the floorplan checks | `tools/placement.py` — `board_a()` returns `Part` objects with `.ref .value .fp .layer .x .y .r .ang .rot .note .dnp .block` |
| The netlist as intended | `tools/schematic.py` — `nets()` |
| A copper rasteriser at 0.05 mm (PIL + distance transform) | `tools/finish.py` — reuse it |
| Layer SVGs in register and `layers.json` | `viewer/a/layers/`, made by pcbview (`pcbview.toml`; `tools/regen.py --board a`) |
| KiCad Python | `import pcbnew` works on the system `python3` (3.14.4, pcbnew 9.0.8); `kicad-cli` 9.0.8 |
| The specification, draft 0.5 | `spec.html`; the README carries the routing story |
| Sibling firmware | `~/pcb/rp2350-motor-controller/firmware/src/main.cpp`, `tune.py`, `tuned_gains.txt`, `patches/simplefoc_rp2040_current_sense.{h,cpp}`, `CLAUDE.md`, `platformio.ini` |
| Sibling reviews | `~/pcb/rp2350-motor-controller/review/{findings,power,gan,schematic}.html` |
| MT6701 datasheet | `~/pcb/rp2350-motor-controller/hardware/encoder/docs/2109011830_Magn-Tek-MT6701CT-STD_C2856764.pdf` |
| EG3113 datasheet (the sibling's driver, for comparison) | `~/pcb/ebike_controller/rp2040-motor-controller/docs/gate_drive/` |

Board origin: KiCad (148, 105) mm is the shaft axis and the MT6701 sensing centre; aux
and grid origins are set there. Angles in the tools are measured from +x,
counter-clockwise, top view (outward face). B.Cu is the motor-facing face.

### 1.2 Geometry

| Item | Value |
|---|---|
| Board | Ø65.0 mm, 1.6 mm, 6 layers, copper pullback 1.0 mm (R_USABLE 31.5) |
| Motor mount | 4 × Ø3.2 **NPTH** at (±12.5, 0), (0, ±9.5). No copper: not a ground bond |
| Perimeter bosses | 6 × M2.5 at R 29.5, angles 0/68/136/204/256/308°; Ø4.8 copper pads on every layer, mask open both sides. Standoff, heat path and chassis-ground bond (the aluminium ring clamps here) |
| Sections | Phase cells A, B, C of 68°, centred at **34°, 102°, 170°**; utility wedges of 52° centred at 230° (power link), 282° (CPU), 334° (signal link) |
| Heatsink land | Bare F.Cu, R 29.2–31.5, one ~56° arc per phase cell plus the boss pads. Nothing but GND may be under it |
| Lead pads | `PhasePad_Arc` on B.Cu, ≈ R 28.5–31.3, ±7° about the cell axis; 14 AWG leads |
| Centre | Nothing but the encoder inside R 16; MT6701 (SOIC-8) at (0, 0) on B.Cu; Ø12 magnet keepout on the motor side |
| Magnet | Ø8 × 2.5 mm diametric (geometry.py; the MT6701 datasheet recommends Ø6 × 2.5), air gap 1.5 mm (datasheet 0.5–2.0, typ 1.0) |
| Stack | Motor rear face → board A 10.75 mm (5.0 shaft + 2.5 magnet + 1.5 gap + 1.75 body); board A → board B 11.0 mm on the six bosses |

### 1.3 Stackup, from the board file

| Layer | Thickness | Content |
|---|---|---|
| F.Cu | 70 µm (2 oz) | FET drains and switch-node islands, DC-link pads, gate drive, GND pour |
| prepreg | **0.100 mm**, FR4 εr 4.5, tanδ 0.02 | the number the 0.39 nH estimate rests on |
| In1.Cu | 35 µm | **GND, solid** |
| core | 0.367 mm | |
| In2.Cu | 35 µm | **VBUS sector** under the phase cells; **+3V3** on the centre disc and CPU wedge; GND elsewhere |
| core | 0.367 mm | |
| In3.Cu | 35 µm | signals + GND fill (the only signal layer that crosses the board) |
| core | 0.367 mm | |
| In4.Cu | 35 µm | **GND, solid** |
| prepreg | 0.100 mm | |
| B.Cu | 70 µm (2 oz) | switch-node pours (to R 20), phase-output pours and lead pads, shunts, sense amplifiers, encoder |

Mask 10 µm per side. Via plating 25 µm. JLCPCB 6-layer, via-in-pad filled and capped
(POFV) — treat the fill as non-conductive; the barrel conducts.

Design rules: 0.15 mm track and clearance; **0.4 mm clearance on the 60 V nets** (class
Phase: `VBUS`, `SW_*`, `PHASE_*`); vias 0.5/0.20 signal, 0.6/0.30 power, 0.8/0.40 phase;
hole-to-hole 0.5 mm; FET thermal vias 16 per drain pad, 0.4 mm drill, 0.8 mm pad, 0.95 mm
pitch.

### 1.4 Nets that matter

Power: `VBUS`, `GND`, `+12V` (gate rail, from board B), `+5V`, `+3V3` (plane on In2),
`+3V3A`, `+1V1`.

Per phase X ∈ {A, B, C}: `HIN_X`, `LIN_X` (CPU → driver); `HO_X`, `LO_X` (driver → gate
resistor); `GH_X`, `GL_X` (gate resistor → gate, with the 10 k bleed); `VB_X` (bootstrap);
`SW_X` (switch node: F.Cu island between the FETs, B.Cu pour reaching in to R 20 with
half-width 10 mm); `PHASE_X` (B.Cu pour R 25.9–28.9 across ±11.5 mm plus the lead pad);
`SNSP_X`, `SNSN_X` (sense taps); `ISENSE_A`, `ISENSE_B` (amplifier out → ADC0, ADC1).

Sense and CPU: `VBUS_SENSE` (ADC2), `FET_TEMP` (ADC3), `ENC_SCK/CS/DO/OUT` (SSI, on the
same board — no line drivers), `USB_DP/DM`, `RS485_*`, `SWCLK/SWDIO`, `RUN`.

**Where the 20 A goes.** Confirmed with pcbnew on 2026-09-11: `VBUS` has exactly one
zone, on In2, and no tracks. The high-side drain pads reach it only through their 16-via
arrays (footprint pads with drills, not PCB vias) and the DC-link capacitor pads through
via-in-pad (13 PCB vias on VBUS in total). `GND` from the low-side source pads goes down
to In1 by via-in-pad. So the commutation loop is **not** "F.Cu over In1 at 0.1 mm"
throughout: its VBUS leg runs on In2, 0.5 mm below F.Cu, with In1 in between, and enters
F.Cu through a 4 × 4 via field whose antipads perforate the In1 return plane. That is
hypothesis H1 in §4.

### 1.5 Phase cell A, as placed

From `tools/placement.py` on 2026-09-11. Radius in mm from the shaft axis, angle in
degrees from +x, rotation as placed. Cells B and C are the same, rotated by +68° and
+136°. Bolts at 0° and 68°; cell axis 34°.

| Ref | Value | Layer | R | Angle | Rot | Role |
|---|---|---|---|---|---|---|
| C101 | 2.2 µF / 100 V, 1206 | F.Cu | 24.80 | 5.26 | 0 | DC-link bulk ceramic, behind the 100 n |
| C103 | 100 n / 100 V, 0603 | F.Cu | 24.80 | 10.30 | 0 | DC-link HF, at the high-side drain |
| Q1 | BSC030N08NS5 | F.Cu | 26.10 | 21.60 | −90 | **high side** (drain = VBUS via 16 vias to In2; source = SW) |
| Q2 | BSC030N08NS5 | F.Cu | 26.10 | 46.40 | −90 | **low side** (drain = SW; source = GND via-in-pad to In1) |
| C104 | 100 n / 100 V, 0603 | F.Cu | 24.80 | 57.70 | 0 | DC-link HF, at the low-side source |
| C102 | 2.2 µF / 100 V, 1206 | F.Cu | 24.80 | 62.74 | 0 | DC-link bulk ceramic |
| U1 | EG2103, SOIC-8 | F.Cu | 19.90 | 34.00 | 90 | gate driver, on the cell axis |
| R101 | 2.2 Ω, 0402 | F.Cu | 19.90 | 48.19 | 90 | gate, high side (damping, not edge shaping) |
| R102 | 2.2 Ω, 0402 | F.Cu | 19.90 | 54.41 | 90 | gate, low side |
| C105 | 1 µF / 25 V, 0603 | F.Cu | 19.90 | 60.06 | 0 | bootstrap; SW pad over the pour, via |
| R111 | 4.7 k, 0402 | F.Cu | 19.90 | 19.81 | 90 | HIN pull-down to GND |
| R112 | 4.7 k, 0402 | F.Cu | 19.90 | 13.59 | 90 | LIN pull-up to +3V3 (coast at reset) |
| C106 | 100 n, 0603 | F.Cu | 19.90 | 7.94 | 0 | VCC decoupling at the driver |
| D101 | "100 V fast", SOD-323 | B.Cu | 19.55 | 64.77 | 0 | bootstrap diode (no part number yet) |
| R109 | 10 k, 0603 | B.Cu | 20.85 | 49.58 | 0 | G–S bleed, high side, via through both pads |
| R110 | 10 k, 0603 | B.Cu | 23.90 | 55.80 | 0 | G–S bleed, low side |
| R105 | 1.6 mΩ, 2010 | B.Cu | 24.85 | 35.50 | −1.5 | inline shunt, SW pad over the SW pour, PHASE pad in the PHASE pour |
| R106 | 1.6 mΩ, 2010 | B.Cu | 24.85 | 27.66 | 6.3 | inline shunt, parallel with R105 (0.8 mΩ) |
| R107 | 10 Ω, 0603 | B.Cu | 19.30 | 20.67 | 0 | sense tap, SW side (SNSP) |
| R108 | 10 Ω, 0603 | B.Cu | 25.00 | 51.53 | 180 | sense tap, PHASE side (SNSN) |
| C108 | 1 n, 0603 | B.Cu | 19.30 | 25.90 | 0 | differential filter SNSP–SNSN |
| U4 | INA241A3, TSOT-23-8 | B.Cu | 19.30 | 34.00 | 180 | 50 V/V, 1.65 V reference |
| D102 | TPSMF4L64A, SOD-123FL | B.Cu | 29.80 | 46.50 | 90 | phase clamp to GND, beside the lead pad |
| R901 | 10 k NTC, 0603 | B.Cu | 18.50 | 15.11 | 180 | FET temperature (cell A only) → ADC3 |
| J1 | PhasePad_Arc | B.Cu | ≈28.5–31.3 | 34 ± 7 | | lead pad |

The cell's topology: the two 2.2 µF sit at the two ends of the cell (5° and 63°), the two
100 n beside the high-side drain and the low-side source (10° and 58°), the FETs at 21.6°
and 46.4° with the switch-node island between them. The high-frequency loop therefore spans
roughly 48° of arc at R 24.8–26.1 (≈ 21 mm), VBUS-fed from In2, GND-returned on In1.

Netlist of the cell (from `tools/schematic.py`): Q1 pins 1–3 = SW, 4 = GH, 5 = VBUS;
Q2 pins 1–3 = GND, 4 = GL, 5 = SW; C101–C104 VBUS–GND; R105/R106 SW–PHASE (cell C:
0 Ω); D102 PHASE–GND; U4 pin 1 SNSN, 2–4 GND, 5 ISENSE, 6–7 +3V3, 8 SNSP; R107 SNSP–SW;
R108 PHASE–SNSN; C108 SNSP–SNSN; R109 GH–SW, R110 GL–GND; R101 HO–GH, R102 LO–GL; C106 +12V–GND; R111 HIN–GND;
R112 LIN–+3V3.

### 1.6 What is *not* on the board

- **No RC snubbers** on the switch nodes (the sibling has them; this board decides after
  measurement — this simulation is that measurement).
- **No PNP turn-off booster and no gate clamp diodes.** Spec §3 says their footprints were
  kept; the captured power-stage sheet has none. Treat the spec as stale on that point and
  say so in the findings.
- **No RC between the INA241 output and the ADC pin** and no anti-alias filter anywhere in
  the current-sense chain.
- **No fourth half-bridge** → no brake chopper. Regen has only board B's bulk and the TVS.
- **Board B is an outline** and five empty sheets: bulk, bus TVS, both LMR38010 bucks, the
  LTC4359 ideal diode, USB-C, RS-485. Model it lumped (§3.4).
- No Y capacitors; no frame bond except the six M2.5 bosses.

---

## 2. Operating conditions and the firmware model

### 2.1 Design point (`tools/geometry.py`)

| Quantity | Value |
|---|---|
| Bus | 60 V nominal; 80 V silicon; phase TVS TPSMF4L64A (64 V standoff, breakdown 71–79 V); board B bus TVS SMDJ64A |
| Phase current | **20 A RMS continuous per phase**; 28.3 A peak; mean rectified 18.0 A |
| Switching | 20 kHz, three half-bridges, centre-aligned PWM |
| Sense | 0.8 mΩ × 50 V/V = 40 mV/A about 1.65 V; ±36.2 A full scale (INA241 worst-case swing V_S − 0.2 V). Precision mode: one shunt desoldered, 1.6 mΩ, 80 mV/A, ±18.1 A |
| Board A loss | 10.56 W: conduction 5.69, switching 3.84, shunts 0.64, gate 0.14, logic 0.26. At 10 A RMS: 4.12 W |
| Edge rates (driver-limited) | t_on = Q_gd / 0.3 A = 65 ns; t_off = Q_gd / 0.6 A = 32.5 ns; di/dt = 28.3 A / 32.5 ns = 0.87 A/ns; dV/dt ≈ 60 V / 50 ns ≈ 1.2 kV/µs |
| Thermal path | via array 7.6 K/W per FET; spreading 1.0 K/W; ring joint 0.4 K/W; ring to ambient must be ≤ 6.8 K/W (≥ 98 cm²) for T_j ≤ 125 °C |
| Power sources | XT30 60 V battery, or USB-PD 20 V into VMOT through the LTC4359; pre-contract 5 V cannot raise the 12 V gate rail |

Operating envelope to sweep: V_bus ∈ {20, 48, 60} V; I_phase ∈ {0, 5, 10, 20} A RMS with
28.3 A peak edges; T_j ∈ {25, 125} °C; edge speed nominal and 2× faster (a stronger driver
is the spec's named escape).

### 2.2 The firmware, as inherited from the sibling

All read from `~/pcb/rp2350-motor-controller/firmware` on 2026-09-11. SimpleFOC 2.3.5
(`askuric/Simple FOC@^2.3.5`), arduino-pico (earlephilhower) core, `build_type = debug`,
`lib_ignore = FreeRTOS`, `-DSIMPLEFOC_PWM_LOWSIDE_ACTIVE_HIGH=false` (active-low LIN —
same convention on EG2103).

| Item | Sibling value | Source |
|---|---|---|
| Driver | `BLDCDriver6PWM`, `pwm_frequency = 20000`, `dead_zone = 0.02` (2 % of the period = **1.0 µs per edge, in software**, applied in `swDti()`), `voltage_power_supply` read from the VMOT ADC (30 V initial) | `main.cpp:718-720`, SimpleFOC `rp2040_mcu.cpp:218-242` |
| PWM mode | `pwm_set_phase_correct(slice, true)` — centre-aligned; wrap and clkdiv from the frequency | `rp2040_mcu.cpp:76-78` |
| Modulation | `foc_modulation` never set → **SinePWM** (not SVPWM), `modulation_centered = 1` (phases centred on V_supply/2) | `main.cpp` (absent), SimpleFOC defaults |
| Torque control | `TorqueControlType::foc_current`; motion `MotionControlType::velocity` | `main.cpp:593-594` |
| Current loop, tuned 2026-05-15 | P = 0.36, I = 1.8, output_ramp 0, LPF Tf = 5 ms (both Iq and Id) | `tuned_gains.txt` |
| Current loop, code defaults (MT6701 build) | P = 0.6, I = 0.3, Tf = 20 ms | `main.cpp:595-600` |
| Velocity loop, tuned | P = 0.708, I = 3.185, D = 0, output_ramp 200, Tf = 10 ms | `tuned_gains.txt` |
| Limits (bench) | `voltage_limit` 4 V, `current_limit` 4 A (clamped below the sense saturation, `CURRENT_LIMIT_MAX_A = 0.98 × 1.65 V / (R_shunt × 20)`), `velocity_limit` 20 rad/s, `voltage_sensor_align` 1.0 V | `main.cpp:587-592` |
| Loop rate | `loopFOC()` + `move()` ≈ **20 kHz** when nothing prints; 407 Hz when a CSV row prints per iteration | `CLAUDE.md` |
| Current sense (sibling) | `InlineCurrentSense(SHUNT, 20, …)`, INA240A1 20 V/V, 20 mΩ (±4.1 A) or 10 mΩ; gains and phase mapping found by `driverAlign()` and stored in LittleFS | `main.cpp:2111` |
| ADC engine | RP2350 ADC free-running at `clkdiv 0` (≈ **500 ksps**), **round-robin over the enabled channels** (Ia, Ib, Ic, VMOT = 4 → each channel refreshed every ≈ 8 µs), 12-bit, 3.3 V, DMA ring buffer, **no synchronisation to the PWM**, no averaging; `loopFOC()` reads whatever the last conversion was | `patches/simplefoc_rp2040_current_sense.cpp` |
| Bus guard | fold `current_limit` to zero across 63 → 66 V, restore below; runs every `loop()` at ≈ FOC rate | `main.cpp:104-105, 449-490` |
| Brake chopper | 4th leg, 15 Ω / 100 W, on 64 → 66 V, 95 % max duty, 300 J budget — **not available on servodrive** | `main.cpp:106-113` |
| VMOT sense | 100 k / 5.1 k divider (servodrive: 2 × 56 k / 4.7 k → 2.42 V at 60 V) | `main.cpp:72-74` |
| Reset state | sibling: 10 k pull-downs on both driver inputs → **low sides on, motor shorted** at every reset; servodrive: 4.7 k up on LIN → **coast** | spec §9 |
| Alignment | `voltage_sensor_align` reduced 2.0 → 1.0 V because 2.0 V saturated a ±4.1 A sense chain | `main.cpp:588` |
| Encoder | MT6701, 14-bit SSI over SPI0 (sibling: through SIT3088 transceivers, response shifted 2 bytes/1 bit; servodrive: on the same board, no shift) | `CLAUDE.md` |

**Servodrive deltas to apply in the model.** GPIO 8/9, 10/11, 12/13 are PWM slices 4, 5,
6 with both channels at the same duty (EG2103 inverts LIN internally; `B_INV` clear).
ADC0/1 = I_a/I_b, ADC2 = V_bus, ADC3 = FET NTC; I_c = −(I_a + I_b). INA241A3 at 50 V/V on
0.8 mΩ → 40 mV/A. No fourth leg. EG2103 provides interlock and a 560 ns internal dead time
(turn-on delay 780 ns vs turn-off 220 ns, so the effective dead time is that asymmetry;
input pulses shorter than ≈ 560 ns produce no output → duty 0–1.1 % and 98.9–100 %
unreachable at 20 kHz). The software `dead_zone` can therefore go to ≈ 0, and whether it
should is Q9.

### 2.3 The sampling model the simulation must reproduce

- Conversion: 96 ADC clocks at 48 MHz = 2 µs per sample; free-running; N channels in
  round-robin; a channel's value is 0–(2N) µs stale when `loopFOC()` reads it.
- No anti-alias filter: the INA241 (bandwidth ≈ 1 MHz class — take the A3 grade's number
  from the datasheet) drives the ADC pin directly. Every switching transient that has not
  settled when a conversion lands on it is a corrupted sample. With six switch-node edges
  per 50 µs period and a sampling aperture t_ap per conversion (the SAR's track phase, a
  few ADC clocks — take it from the RP2350 datasheet, not the full 96-cycle conversion),
  the fraction of corrupted samples is ≈ 6 × (t_settle + t_ap) / 50 µs unless sampling is
  synchronised. The system model (§5, level 4) must carry this statistically, with the
  transient waveform from level 3.
- Quantisation 12 bit over 3.3 V: 0.806 mV = 20 mA per LSB at 40 mV/A (10 mA in precision
  mode). RP2350 ADC DNL/INL: take from the RP2350 datasheet; report but do not model
  beyond ±1 LSB unless it shows up.
- A PWM-synchronised alternative (RP2350: a DMA channel paced by the PWM slice's wrap DREQ
  writing `START_ONCE` to ADC_CS, one conversion per phase at the counter's zero, when all
  low sides are on and the current equals its average) is the firmware recommendation the
  simulation should either justify or dismiss with numbers (Q8).

---

## 3. Motor model

The motor is a parameter set, not a part. Two named sets, plus sweeps.

### 3.1 Set "bench" — what the sibling actually ran

Derived, with the derivation shown so it can be redone:

| Parameter | Value | How derived |
|---|---|---|
| Pole pairs | **11** | `#define POLE_PAIRS 11` in `main.cpp:117` (both configs) |
| Phase resistance R (line-to-neutral, as SimpleFOC sees it) | **0.25–0.5 Ω** | `voltage_sensor_align` 2.0 V saturated the ±4.1 A chain and 1.0 V did not (`main.cpp:588-590`, `CLAUDE.md`), so I(2 V) ≳ 4.1 A and I(1 V) ≲ 4.1 A |
| R, second bracket | 0.01–0.15 Ω | tuner: K_i = ω_c·R with K_i = 1.8 and ω_c ∈ {200, 100, 50, 25, 12.5} rad/s (`tune.py:354-470` halves the bandwidth on overshoot) — inconsistent with the row above; the tuner's DC-gain estimate is unreliable with the 5 ms LPF and serial-throttled loop in the path. Use the row above; note the disagreement |
| Phase inductance L | **unknown; sweep 0.1–2 mH** | the tuner's L = τ·(R + P) includes the 5 ms filter time constant and is not a motor property |
| Back-EMF constant | unknown; sweep so that rated speed at `velocity_limit` 20 rad/s uses ≤ 4 V | `voltage_limit` 4 V, `velocity_limit` 20 rad/s |
| Supply on the bench | 15–30 V (`DEMO_MIN_VMOT` 15 V; `voltage_power_supply` 30 V initial) | `main.cpp:219, 720` |
| Current | ≤ 4 A (`current_limit`), shunts 20 mΩ | `main.cpp:591` |

This set exercises the control model at the sibling's gains and confirms the system model
against the sibling's measured loop behaviour (≈ 20 kHz loop, `tuned_gains.txt`). It does
not stress the power stage.

### 3.2 Set "design point" — what the servodrive is built for

20 A RMS at 60 V with SinePWM (phase amplitude ≤ V_bus/2 = 30 V → 21.2 V RMS per phase,
≈ 1.27 kW at unity power factor). A plausible 1 kW-class BLDC for that operating point,
stated as ranges to sweep, **not** as a chosen motor:

| Parameter | Range | Rationale |
|---|---|---|
| Pole pairs | 7, 11, 14, 21 | 11 from the sibling; the others bracket common outrunners |
| R (line-to-neutral) | 20–60 mΩ | I²R at 20 A = 8–24 W per phase, 2–6 % of output |
| L (line-to-neutral) | 20–150 µH | L/R ≈ 0.5–3 ms |
| Back-EMF | such that 21 V RMS phase is reached at rated speed; sweep rated speed 1 000–4 000 rpm | sets the electrical frequency 120–1 500 Hz → current-loop and sampling ratios |
| Winding-to-frame capacitance | 100 pF – 2 nF | common-mode path (Q12) |
| Lead length, board → motor | 0.05–0.5 m | radiated and CM (Q11, Q12) |
| Rotor stray field at the shaft end | 0–5 mT, dipole-like, rotating with the rotor | encoder (Q10) |
| Inertia J, damping | sweep 1e-4 – 1e-2 kg·m², small viscous term | velocity loop only |

### 3.3 Electrical model of the motor for levels 3 and 4

Three-phase wye, per-phase R and L (constant, no saturation — say so), sinusoidal
back-EMF with the electrical angle from the mechanical model, neutral floating.
Level 3 (SPICE) uses it as the load of one cell with the other two phases as ideal
sources at the commanded duty; level 4 (system) uses the dq model with the same numbers.

### 3.4 Board B, lumped

| Element | Model | Basis |
|---|---|---|
| Bulk | 4 × 100 µF / 100 V polymer-hybrid: C 100 µF each, ESR 20–40 mΩ each, ESL 3–5 nH each; sweep 3 × 100 µF electrolytic (ESR 0.2 Ω, the spec's original) as the bad case | spec §8 |
| Bus TVS | SMDJ64A: capacitance from datasheet, clamp 71–79 V | spec §7 |
| Power link | 2 × (2×5) 2.54 mm headers, 10 VBUS + 10 GND pins; mated pin length from the chosen header (assume 6 mm mated, 0.64 mm square pins) → extract L and R per pin pair with the same solver as the board; plus six M2.5 brass standoffs (11 mm) in parallel with the ground pins — model each as a wire with a contact resistance 1–10 mΩ | spec §8 |
| Bucks | LMR38010 ×2: constant-power loads 1.2 W (12 V × 0.1 A) and 2.5 W (5 V × 0.5 A) with input ceramics 4.7 µF each; not switched in the model unless a bus-ripple result asks for it | spec §7 |
| Source | XT30: 60 V behind 50 mΩ + 1 µH (cable); or USB-PD 20 V behind the LTC4359 | spec §7 |

---

## 4. Questions the simulation must answer

Each question names the current estimate, the method (level, §5.1), the output, the
pass/fail criterion, and the decision it feeds. Hypotheses H1–H4 are things this spec
suspects are wrong in the design's own arithmetic; test them explicitly and report the
verdict either way.

**H1 — the commutation loop is bigger than 0.39 nH.** `geometry.commutation_loop()` models
a 15.4 × 5 mm strip 0.1 mm above In1. But VBUS reaches the high-side drain from In2, 0.5 mm
below F.Cu, through 16 vias whose antipads perforate In1; the cell's HF loop spans ≈ 21 mm
of arc. Expect the PCB part to be 0.8–1.5 nH rather than 0.39, total ≈ 2.5–3 nH, overshoot
≈ 2–3 V rather than 1.7. Still fine if so — but the number in the spec is wrong.

**H2 — the DC-link ceramics are not 13 µF at 60 V.** Six 2.2 µF / 100 V 1206 X7R at
60 V bias typically retain 40–60 %. The interconnect ripple split (spec §8) assumed 13 µF
and got 23.2 A RMS on a 30 A link; at 6 µF the share crossing the header rises. Also the
100 n / 100 V 0603s at 60 V.

**H3 — the shunt's ESL dominates the sense signal during edges.** Full-scale signal at
28.3 A is 22.6 mV across 0.8 mΩ. A 2010 shunt pair has ESL of order 0.2–0.5 nH; at
0.87 A/ns that is 170–430 mV of L·di/dt — 8–20× the signal — before the 10 Ω + 10 Ω / 1 nF
filter (f_c ≈ 8 MHz) and the INA241's bandwidth. Plus mutual inductance from the
commutation loop into the tap loop (the taps are 5 mm apart in radius, on opposite sides
of the cell).

**H4 — the two sense taps are not symmetric.** R107 (SNSP, at R 19.3, 20.7°) and R108
(SNSN, at R 25.0, 51.5°) follow different paths to the amplifier at R 19.3, 34°: different
lengths, different capacitance to the SW pour and to GND. The switch node slews 60 V in
≈ 50 ns; any asymmetry converts common-mode into differential.

| # | Question | Estimate today | Method | Output | Pass if | Decision it feeds |
|---|---|---|---|---|---|---|
| **Q1** | Commutation-loop inductance and resistance per cell, 1 kHz–300 MHz, including packages, cap ESL and the via fields | 2.0 nH total (0.39 PCB + 1.0 pkg + 0.6 ESL) | L1 quasi-static (FastHenry2) on the extracted copper; L2 (openEMS) cross-check on cell A | L(f), R(f), current-density plots on In1/In2 under the loop; H1 verdict | reported; L2 within 25 % of L1 | snubber (Q3), cap placement (hand-back to `placement.py` R_DCLINK / cap order) |
| **Q2** | V_ds overshoot and ringing at turn-off, 28.3 A, 60 V, both FETs; V_ds peak vs Rg ∈ {2.2, 4.7, 10, 22 Ω}, T_j 25/125 °C | 1.7 V → 61.7 V peak; ring f ≈ 1/(2π√(L·C_oss)) ≈ 100 MHz | L3 SPICE, cell with Q1 parasitics, VDMOS fitted to BSC030N08NS5, EG2103 behavioural | waveforms, V_peak table, ring frequency and Q | **V_ds,peak ≤ 68 V** worst case (TVS never conducts: breakdown min 71 V); ringing decays to < 5 % in ≤ 5 cycles | snubber yes/no and values; Rg value |
| **Q3** | RC snubber need and value | none fitted | L3 sweep R ∈ {2.2–22 Ω}, C ∈ {0.47–4.7 nF} with power in R | V_peak, ring Q, snubber loss at 20 kHz | if Q2 fails: smallest snubber that passes with P_R ≤ 0.25 W | add snubber footprints (hand-back: 2 parts per cell, 0805) or not |
| **Q4** | Gate-loop parasitics and Miller-induced turn-on of the off FET during the complementary edge | not estimated; Rg 2.2 Ω, 10 k bleed, driver 0.3/0.6 A | L1 for the gate loops (HO/LO → Rg → gate pad → source → driver GND, incl. the bleed via through both pads); L3 with C_gd(V) | L_gate, induced V_gs peak vs dV/dt, V_gs ringing | induced V_gs,peak ≤ 0.7 × V_gs(th),min at 1.2 kV/µs and at 2× that; V_gs overshoot ≤ 20 % | Rg; whether the (unfitted) PNP booster or a Miller clamp needs footprints; hand-back to `fanout.py` gate arcs if L_gate is the problem |
| **Q5** | Sense-chain transient error: L·di/dt across the shunt pair, mutual coupling into the SNSP/SNSN loop, tap asymmetry (H3, H4), through R107/R108/C108, the INA241 (bandwidth, slew, CMRR vs frequency, PWM-rejection figure) to the ADC pin | not estimated | L1 (partial and mutual L of shunts and taps; C of taps to SW and GND via FastCap2), L3 (INA241 behavioural), L2 cross-check of the tap-loop mutual inductance | ISENSE waveform after each edge, settling time to ±1 LSB, sample-corruption fraction at 125 ksps unsynchronised | **settles to ±1 LSB (0.8 mV) within 500 ns** of the switch-node edge, both edges, both current polarities; corrupted-sample fraction ≤ 6 % | tap placement (hand-back), filter values (R107/R108/C108), an ISENSE RC, PWM-synchronised sampling (Q8) |
| **Q6** | DC and low-frequency sense accuracy: effective resistance between the tap points including pour copper, its temperature coefficient (copper 0.39 %/K vs the shunt's), current-sharing between R105 and R106, and the same for cell C's 0 Ω links | 0.8 mΩ, 50 ppm/K assumed | L5 conduction solve on the raster (6 layers + vias) at 28 A | R_tap-to-tap, share of copper in it, TCR, per-shunt current | copper share ≤ 5 % of 0.8 mΩ; TCR of the total ≤ 0.05 %/K; R105/R106 share within 10 % | tap positions; whether to Kelvin the taps onto the shunt pads (hand-back to `placement.py` S_TAP_PH / `fanout.py` sense arcs) |
| **Q7** | Current density and I²R in the 20 A copper at 20 A RMS: switch-node islands, phase pours (the band is 95 A/mm² by the spec's own arithmetic), lead pads, the 16-via arrays (sharing), the shunt pads | IPC-2152 wants ≈ 6 mm of 2 oz; band is 3.0 mm | L5 | J maps per layer, hot-spot list, per-via current, resistance lead pad → FET | max via current ≤ 2 A RMS (0.4 mm drill, 25 µm plating); local Joule density reported; no single hot spot > 3× the band's mean | pour widths (hand-back), via counts (`FET_VIA_N`), whether the phase band must widen |
| **Q8** | Sampling: with the transient from Q5 and the 20 kHz ripple, what does the free-running 125 ksps/channel ADC deliver to the current loop, vs PWM-synchronised sampling at the counter zero | none | L4 system model, Monte-Carlo over sample phase | current-loop noise floor (A RMS), bias, spectral content; same for synchronised sampling | synchronised sampling shown to cut corrupted samples to 0 and noise by a stated factor | firmware recommendation (DMA-paced ADC trigger from the PWM wrap) |
| **Q9** | Dead time: software `dead_zone` 0.02 (1 µs) plus EG2103's 560 ns; voltage distortion (V_bus × t_dead / T = 1.9 V with, 0.67 V without the software term), 6th-harmonic torque ripple, min-pulse clipping at the duty extremes; loop behaviour with `dead_zone` = 0 | spec: "can go to roughly zero" | L4 with the SimpleFOC control law, both motor sets | current THD, torque ripple, Iq error vs speed and current; stability margins | recommendation with numbers | firmware: `dead_zone` value and dead-time compensation |
| **Q10** | Field at the MT6701: (a) the magnet's B at the IC over air gap 1.0–2.0 mm and ±0.3 mm off-axis; (b) stray field from the three phase currents in the pours, lead pads and leads (Biot–Savart from the level-5 current distribution) at 28.3 A; (c) rotor leakage, parametric 0–5 mT; → angle error vs rotor angle and current → torque ripple through the loop | none | L6 (magpylib); L4 for the ripple consequence | B_mag(gap), B_stray vectors, angle error (deg) vs electrical angle, LSB equivalent (14-bit = 0.022°/LSB) | B_mag within 20–100 mT over the gap tolerance; **current-induced angle error ≤ 0.05° (≈ 2 LSB) at 28.3 A**, or reported with its torque-ripple cost | lead routing rule (where the three leads leave), magnet grade, whether the adjacent-cell layout (0–204°) needs a compensating term in firmware |
| **Q11** | Near and far field of the switching: H-field map 3 mm above both faces at 20 kHz harmonics and at the ring frequency; coupling into the encoder SSI lines, USB, RS-485, the CPU wedge; radiated E at 3 m (motor lead as a 0.5 m antenna) | none | L2 openEMS (whole board, ports on victims; NF2FF) | field maps, S-parameters SW → victims, dBµV/m vs frequency against CISPR 32 class B limits as a reference | informational; any victim receiving > 100 mV pk from an edge is a finding | shielding/enclosure notes; encoder trace routing (`fanout.py`) |
| **Q12** | Common-mode current through the motor's winding-to-frame capacitance from dV/dt, its return path (frame → ? → board GND: the M3 mounts are NPTH; only the ring/bosses bond), bus-side CM at the XT30 | none | L3 with the parametric C_wf and a lumped frame path | I_cm peak and RMS vs C_wf and lead length; voltage between motor frame and board GND | reported; frame-to-GND excursion ≤ 10 V pk | Y-cap / frame-bond recommendation for the enclosure |
| **Q13** | Bus ripple and the interconnect at the design point: ripple-current split between board A ceramics (H2-derated) and board B bulk through the header + standoffs; resonance of header L with the ceramics; V_bus ripple at the FET drains; header pin current | 12.4 A RMS ripple, 75 % crosses, 23.2 A RMS on 30 A; ripple ≈ 3 V | L1 (header, standoffs) + L3 (whole DC link, three cells switching with SinePWM at m = 0.8) | I_link RMS, V_bus,pp at the drains, impedance plot of the DC link seen from a cell | I_link ≤ 80 % of rating; V_bus,pp ≤ 3 V; no DC-link resonance with Q > 3 below 1 MHz | header pin count; ceramic count and value (hand-back to `placement.py`/`schematic.py`); board B bulk spec |
| **Q14** | Regen and the coast/brake question: a 20 A decel event pumping the bus (0.5·C·(71² − 60²) = 0.22 J at 300 µF); time to TVS conduction; TVS energy; the bus-guard fold-back timing at ≈ 20 kHz | none for this board | L4 with the bus model | V_bus(t), TVS energy per event, what the 63–66 V guard can and cannot catch | reported | brake resistor / active clamp / bulk size (spec §11 questions 7 and 3) |

Out of scope, and say so in the report: the RP2350 core buck (VREG_LX, 3.3 µH) and its
spurs on `+3V3A`; USB and RS-485 signal integrity; a motor FEA (no motor); board B's own
layout (none exists); thermal beyond the coupling in §6 P8.

---

## 5. Simulation architecture and tools

### 5.1 Levels

| Level | Physics | Tool | Used for |
|---|---|---|---|
| L0 | closed form | `tools/geometry.py` | the baseline every result is compared with |
| L1 | magneto-/electro-quasi-static PEEC | **FastHenry2** (partial and mutual L, R(f) with skin and proximity), **FastCap2** (C) | Q1, Q4, Q5, Q13 — the workhorse. Valid here: the board is 65 mm, λ/15 at 300 MHz in FR4 |
| L2 | full-wave FDTD | **openEMS** (+ CSXCAD, Python interface) | Q1 cross-check, Q5 cross-check, Q11 (near field, S-parameters, NF2FF) |
| L3 | circuit, transient and AC | **ngspice 45** (apt), driven from Python by writing netlists and reading raw files (`libngspice.so` is already installed for KiCad; the CLI is not) | Q2, Q3, Q4, Q5, Q12, Q13 |
| L4 | system: inverter + motor + SimpleFOC control law + sampling | **Python/numpy/scipy** (own code, `sim/loop/`) | Q8, Q9, Q10 (consequence), Q14 |
| L5 | DC/LF conduction on multilayer copper with vias | own finite-difference solver on the 0.05 mm raster (`tools/finish.py` already rasterises), sparse solve with scipy + **pyamg**; or gmsh + **scikit-fem** if the raster is too coarse at the shunt pads | Q6, Q7, and the current sources for Q10 |
| L6 | magnetostatics of magnets and currents | **magpylib** | Q10 |
| L7 | thermal (optional, P8) | scikit-fem, or Elmer in Docker if 3-D detail is needed | via array and spreading resistances, T_j at 20 A |

### 5.2 What is on this machine (checked 2026-09-11)

Present: Python 3.14.4 with numpy, scipy, matplotlib, sympy, pcbnew (9.0.8); kicad-cli
9.0.8; `libngspice.so.0` (KiCad's); pdftotext; wine; docker; `uv`, `pip`, `apt-get`,
`sudo`; 24 cores, 89 GB RAM; an RTX 3060 whose driver currently mismatches its library
(`nvidia-smi` fails) — do not plan on the GPU.

Absent: ngspice CLI, openEMS/CSXCAD, FastHenry/FastCap, FEMM, gmsh, Elmer, ParaView,
shapely, meshio, scikit-rf, PySpice, magpylib.

### 5.3 Installation plan (P0)

```sh
sudo apt-get install -y ngspice gmsh paraview            # ngspice 45.2, gmsh 4.14, paraview 6
pip install --user magpylib shapely meshio scikit-fem pyamg h5py cython
# FastHenry2 / FastCap2 (FastFieldSolvers' maintained forks; C, build with make):
#   git clone https://github.com/ediloren/FastHenry2  && make -C FastHenry2/src
#   git clone https://github.com/ediloren/FastCap2    && make -C FastCap2/src
# openEMS: the documented source build, into ~/opt/openEMS with the Python interface:
#   sudo apt-get install build-essential cmake git libhdf5-dev libvtk9-dev libboost-all-dev \
#        libcgal-dev libtinyxml-dev qtbase5-dev libvtk9-qt-dev
#   git clone --recursive https://github.com/thliebig/openEMS-Project.git
#   cd openEMS-Project && ./update_openEMS.sh ~/opt/openEMS --python
```

Budget one working session for the toolchain. If openEMS will not build, record it and
proceed with L1 + L3 for everything except Q11, which then waits; do not let the toolchain
eat the project. Docker is available if a prebuilt openEMS image is preferred; if used,
mount only `sim/`.

### 5.4 Known-answer tests — each solver, before use

| Solver | Test | Expected |
|---|---|---|
| FastHenry2 | straight round wire, l = 20 mm, d = 1 mm, partial self-inductance | 2·10⁻⁷·l·(ln(2l/r) − 0.75) ≈ 17.4 nH; low-frequency R = ρl/A |
| FastHenry2 | strip 15.4 × 5 mm, 70 µm, 0.1 mm over a wide plane | ≈ µ0·h·l/w = 0.39 nH plus fringing (expect 0.45–0.6 nH); this is exactly `geometry.commutation_loop()`'s PCB term |
| FastHenry2 | two-wire loop | closed form (Grover) within 3 % |
| FastCap2 | parallel plates 10 × 10 mm at 0.1 mm, εr 4.5 | 39.8 pF + fringing |
| openEMS | the same strip over plane as an S-parameter port → L from Im(Z)/ω below 100 MHz | matches FastHenry2 within 10 % |
| openEMS | microstrip line impedance, 0.2 mm wide on 0.1 mm εr 4.5 | closed form (Wheeler) within 5 % |
| ngspice | RLC step: L 2 nH, C 1 nF, R 0.5 Ω | analytic ring frequency and decay |
| ngspice VDMOS fit | I_d–V_ds and C_oss(V), C_rss(V), Q_g(V_gs) vs the BSC030N08NS5 datasheet curves | every point within 20 % over 0–60 V |
| L5 conduction | rectangular strip; annular sector with radial flow (R = ρ·ln(r₂/r₁)/(t·θ)) and tangential flow; a via barrel | analytic within 2 % at the chosen cell size; grid refinement 0.1 → 0.05 → 0.025 mm shows convergence |
| magpylib | dipole far field of the Ø8 × 2.5 magnet; B of a straight wire at 25 mm (µ0·I/2πr = 0.226 mT at 28.3 A) | analytic |
| L4 control | current loop on an RL plant with the sibling's tuned gains reproduces the tuner's step metrics (`tune.py analyze_step`) and the SimpleFOC PID/LPF discretisation exactly | rise/overshoot match to the same metric definitions |

### 5.5 Geometry pipeline (P0)

`sim/extract/` reads the board with `pcbnew` and writes `sim/work/geometry.json`:
polygons per net per layer (zone fills, pads with `GetEffectivePolygon`, tracks as
polygons), vias (position, drill, diameter, layer span, net), the stackup, and a
per-cell crop (cell A: angles −5°…73°, R 15…32.5). From that: (a) FastHenry `.inp`
segment meshes for the loop and gate nets (pours as `G` plane elements with holes for
antipads; tracks as segments; vias as vertical segments), (b) CSXCAD polygons for openEMS,
(c) the layer rasters for L5 (reuse `tools/finish.py`'s rasteriser at 0.05 mm, extend it to
keep net identity per cell), (d) current-path polylines for magpylib.

Cells B and C are rotated copies of A. Simulate A fully; confirm B and C only where the
surrounding copper differs: the signal-link wedge (308–360°) adjoins cell A at 0°, and the
power-link wedge (204–256°), where VBUS and GND enter the board, adjoins cell C at 204°.

---

## 6. Phases and deliverables

Run them in this order. Each phase ends with `sim/results/P<n>.json`, figures in
`sim/report/img/`, entries in `sim/FINDINGS.md`, and one paragraph in the report. Do not
start the next phase while a known-answer test of the current one fails.

| Phase | Work | Deliverable | Gate |
|---|---|---|---|
| **P0 setup** | install (§5.3); `sim/extract/`; known-answer tests (§5.4); `sim/run.py` skeleton; report scaffold linked from `index.html` | tests pass; `geometry.json`; cell-A crop drawn and checked by eye against `img/layers/a/` | all §5.4 tests within tolerance |
| **P1 parasitics** | FastHenry2/FastCap2 on cell A: commutation loop (Q1, H1), gate loops (Q4), shunt + tap loops and mutual terms (Q5, H3/H4), tap capacitances; the header and standoffs (Q13) | L(f), R(f), C tables in `sim/models/parasitics_A.json`; current-density plots on In1/In2; H1 verdict | convergence in segment count reported |
| **P2 cell circuit** | ngspice cell model: VDMOS fit, EG2103 behavioural, bootstrap, caps with ESL/ESR and DC-bias curves (H2), TVS, shunt, taps, INA241 behavioural, ADC pin; Q2, Q3, Q4, Q5 sweeps | waveform sets, V_peak tables, snubber verdict, ISENSE settling | Q2 criterion met or a snubber that meets it |
| **P3 conduction** | L5 on all six layers at 28.3 A per phase pair (A→B, B→C, C→A at the peak instants); Q6, Q7 | J maps, via currents, tap-to-tap R and TCR, hot-spot list | grid convergence |
| **P4 DC link** | Q13 with three cells switching (SinePWM m = 0.8 at 20 A), board B lumped, H2 | I_link, V_bus ripple, impedance plot | criterion in Q13 |
| **P5 encoder field** | magpylib: magnet over gap and misalignment; phase currents from P3 current paths and parametric leads; rotor leakage; Q10 | B at the sensor vs rotor angle and current; angle-error map | Q10 criterion |
| **P6 system** | L4: inverter + motor sets + SimpleFOC law (SinePWM centred, PID with ramp/limit, LPF, `foc_current`, velocity loop) + sampling model (from P2 transients) + dead time; Q8, Q9, Q10 consequence, Q14 | noise floors, distortion, torque-ripple spectra, `dead_zone` recommendation, sampling recommendation, regen timeline | reproduces the sibling's tuned step response with set "bench" |
| **P7 full wave** | openEMS: cell A loop cross-check (Q1), tap mutual cross-check (Q5), whole-board near field and victims (Q11), NF2FF with a lead | field maps, S-parameters, dBµV/m plot | L2 vs L1 agreement stated |
| **P8 thermal (optional)** | Joule sources from P3 into a board thermal model with the ring boundary; verify 7.6 K/W via array and 1.0 K/W spreading | T maps; T_j vs ring K/W | only if P0–P7 are done |
| **P9 report & hand-back** | report page, findings register complete, hand-back list with exact constants and firmware items; a final `python3 sim/run.py` from clean | everything in §0.2 | reproduces |

---

## 7. Component models and material data

Everything in `sim/models/*.json` with source and date. Where a part has no number yet
(the bootstrap diode "100 V fast", the 2.2 µF/100 V 1206, the 100 n/100 V 0603, the
1.6 mΩ 2010, the 2×5 header), pick a representative in-stock JLCPCB/LCSC part, name it, and
flag that the BOM has not chosen one.

| Part | Needed | Notes |
|---|---|---|
| BSC030N08NS5 (Infineon, PG-TDSON-8) | R_ds(on) 3.0 mΩ max at 10 V, ×1.58 at 125 °C; Q_g 76 nC, Q_gd 19.5 nC, C_iss 5600 pF max; C_oss(V), C_rss(V) curves; V_gs(th) min/max; Q_rr 188 nC; body-diode V_f; package L ≈ 0.5 nH source, R_thJC 0.9 K/W | Infineon publishes a PSpice model — try converting; otherwise fit ngspice's VDMOS (`Cgdmax/Cgdmin/a`, `Rds`, `Kp`, `Vto`) to the curves and show the fit |
| EG2103 (EG Micro, SOP-8) | source 0.3 A, sink 0.6 A; t_on 780 ns, t_off 220 ns; dead time 560 ns (460–660); V_IH 2.5, V_IL 1.0; UVLO on ≤ 9.7 V, off ≥ 7.0 V; VB(on) ≤ 9.6 V; LIN internal 200 k pull-up, HIN 200 k pull-down; 600 V level shift dV/dt rating | behavioural: current-limited push-pull with delays and interlock |
| INA241A3 (TI, TSOT-23-8, 50 V/V) | bandwidth at 50 V/V, slew rate, output swing to rails (0.2 V worst), CMRR vs frequency, the "enhanced PWM rejection" CM-step response, input bias current, input R/C | behavioural: gain block with the measured BW and CM-step response; the CM step here is 60 V in 50 ns |
| TPSMF4L64A (Littelfuse, SOD-123FL) | junction capacitance vs voltage, clamp curve | on `PHASE_X` — adds C at the phase node and the lead |
| SMDJ64A | as above | board B |
| 1.6 mΩ 2010 (metal foil/alloy) | ESL, TCR (≤ 50–100 ppm/K typical), 1 % | H3 |
| 2.2 µF / 100 V 1206 X7R; 100 n / 100 V 0603 | C vs DC bias curve, ESR, ESL | H2 |
| 1 µF / 25 V 0603 (bootstrap), 100 n (VCC) | ESR | |
| MT6701 | B_pk at the IC 200–1000 Gauss (20–100 mT); air gap 0.5–2.0 mm; off-axis ≤ 0.3 mm; recommended Ø6 × 2.5 mm magnet; NdFeB TC −0.12 %/°C; 14-bit → 0.022°/LSB; transition noise 0.01° RMS (ABZ); 55 000 rpm max | Q10 |
| Magnet | Ø8 × 2.5 mm diametric, assume N35 (B_r 1.17–1.22 T) and N42 (1.28–1.32 T) | Q10 |
| RP2350 ADC | 12 bit, 500 ksps, 96-cycle conversion, input model, DNL/INL from the datasheet | Q8 |
| Copper | σ = 5.8·10⁷ S/m annealed (use 4.7·10⁷ for plated barrels and ED foil if the fab's data supports it; state which), α = 0.00393 /K | L1, L5 |
| FR4 | εr 4.5, tanδ 0.02 (board file) | L2 |
| Solder mask | εr ≈ 3.5, 10 µm | L2, minor |
| Air gap board A ↔ board B | 11 mm | L2 |

---

## 8. Reporting

### 8.1 Directory layout

```
sim/
  SPEC.md              this document
  FINDINGS.md          the register (§8.3)
  run.py               reproduces everything; `--phase P2` runs one
  extract/             board → geometry.json, FastHenry .inp, CSXCAD, rasters, polylines
  models/              per-part JSON with sources; parasitics_A.json (from P1)
  fasthenry/ fastcap/  inputs and raw outputs
  spice/               netlist templates, ngspice runs, raw parsers
  field/               openEMS scripts
  conduction/          the L5 solver
  loop/                the L4 system model (SimpleFOC law reimplemented, sampling, motor sets)
  encoder/             magpylib scripts
  thermal/             P8, if done
  work/                board copies, meshes, scratch — regenerable, not precious
  results/             P0.json … P9.json — every number the report quotes
  report/              index.html + img/ — static, no server code
```

`results/*.json` is the interface: the report reads only from there, so a re-run can never
show yesterday's number beside today's figure. Keep the JSON flat and named
(`{"Q1": {"L_pcb_nH": …, "L_total_nH": …, "method": "fasthenry", "converged": true, …}}`).

### 8.2 The report page

Static HTML in the project's existing style (see `index.html`, `spec.html`, `style.css`;
light and dark). Sections in the order of §4, one per question: the estimate, the solved
number, the figure, the verdict, the hand-back. A summary table at the top. Link it from
`index.html`'s status page (a one-line addition; nothing else in `index.html` changes).
View it with `proj up servodrive` then `proj url servodrive`. Run `proj doctor` if
anything about serving changes (it should not).

### 8.3 Findings register format

Stable IDs `S-01`, `S-02`, … never renumbered, one row each in `sim/FINDINGS.md`:

```
| ID | Sev | Finding | Evidence | Status | Disposition |
```

Severity HIGH / MED / LOW / INFO as in the sibling's `review/findings.html`. Evidence names
the result key and figure. Status: OPEN, DECIDED, HAND-BACK, VERIFIED-OK. Hypotheses H1–H4
each get a row whatever the verdict. Toolchain failures and unmet criteria are rows too.

### 8.4 The hand-back list

`sim/HANDBACK.md`. Each entry: the result that motivates it, the file and constant
(`tools/placement.py: R_DCLINK`, `tools/fanout.py: …`, `tools/geometry.py: …`), the
proposed value, the expected effect, and what would have to be re-run (`gen_boards.py
--force` then `route.py --rounds 4 --loose` for placement changes — say that this discards
the routing). Firmware items name the SimpleFOC parameter or the RP2350 mechanism.
Enclosure items go to the same list. This file is for a human to decide from; nothing in
`sim/` applies any of it.

---

## 9. Things that will bite

- **Zone fills.** The file carries fills (138 polygons). If a pcbnew script refills, it
  must do so on a copy in `sim/work/`; fills depend on the project's design-rule file
  (`servodrive_A.kicad_pro`) being beside the board.
- **Pad orientation.** Every pad on this board carries its own absolute angle; take
  geometry from `GetEffectivePolygon()`, never from pad size + footprint angle.
- **Flipped footprints.** `PAD::GetLayer()` answers F.Cu for a pad on a flipped part; use
  the layer set. The shunts, amplifier, encoder and bleeds are on B.Cu.
- **Via-in-pad.** 104 stitched vias sit in pads; the FET drain arrays are 16 vias each. A
  via barrel spans all six layers; its antipad on foreign planes is what perforates In1
  under the high-side drain (H1).
- **Net names.** `SW_X` is the switch node, `PHASE_X` is after the shunt. The Phase class
  (0.4 mm clearance) is `VBUS`, `SW_*`, `PHASE_*` and deliberately not `GND`.
- **The design point is RMS.** 20 A RMS per phase, 28.3 A peak. The sense chain is sized
  to the peak; do not mix them (the spec did, twice).
- **Units in the tools are mm and degrees**, KiCad internal units are nanometres, FastHenry
  is whatever the `.units` line says — write it every time.
- **The sibling's firmware labels A/B/C swapped vs its schematic.** Irrelevant here (the
  servodrive netlist is self-consistent), but do not copy pin tables from it.
- **A protected via can come back moved by 25 µm** and a track can end 0.05 mm inside its
  pad — geometry from the file is what was built; do not "clean" it.
- **`python3 tools/geometry.py` rewrites `img/*.svg`.** Harmless but noisy in a diff;
  import it as a module instead (`sys.path.insert(0, 'tools'); import geometry as G`).

---

## Appendix A — the analytic baseline (`tools/geometry.py`, 2026-09-11)

Reproduce by importing the module and calling the functions; do not paste the numbers into
the report — read them from the module at run time so they cannot drift.

| Function | Result |
|---|---|
| `losses()` at 20 A RMS, 20 kHz, 60 V | conduction 5.69 W (3·I²·3.0 mΩ·1.58); switching 3.84 W (e_on = ½·60·18.0·65 ns = 35.1 µJ, e_off 17.6 µJ, e_rr = 188 nC·60 V = 11.3 µJ, ×3×20 kHz); shunts 0.64 W; gate 0.14 W (q_gate = 76 n + 5.6 n·(12−10) = 87.2 nC); logic 0.26 W; **10.56 W** |
| `commutation_loop()` | L_pcb = µ0·0.1 mm·15.4 mm / 5 mm = **0.387 nH**; + 2 × 0.5 nH package + 0.6 nH ESL = **1.99 nH**; di/dt 0.87 A/ns; overshoot **1.73 V**; peak 61.7 V |
| `interconnect(10)` | ripple 12.37 A RMS (m = 0.8, cos φ = 1); bus 21.2 A DC; ceramic 0.612 Ω at 20 kHz vs bulk 0.2 Ω → 75.4 % crosses; link **23.2 A RMS** vs 30 A |
| `bootstrap()` | 1 µF: 0.10 V droop, 1.5 V margin over VB(on) 9.6 V |
| `via_thermal()` | 16 × 0.4 mm: 7.6 K/W (FR4 alone 354 K/W) |
| `sink_needed()` | ring ≤ 6.8 K/W → ≥ 98 cm² at 15 W/m²K |
| Sense | 0.8 mΩ × 50 = 40 mV/A; (1.65 − 0.20)/0.040 = **±36.2 A** vs 28.3 A peak |

## Appendix B — sibling firmware constants, verbatim

```
// main.cpp
#define POLE_PAIRS 11
#define SHUNT_20MOHM 0.020f   // ±4A, 0.4 V/A     (MT6701 build)
#define SHUNT_10MOHM 0.010f   // ±8A, 0.2 V/A     (halls build)
#define CURRENT_AMP_GAIN 20.0f
#define CURRENT_SENSE_SAT_A (CURRENT_SENSE_REF_V / (SHUNT_RESISTOR * CURRENT_AMP_GAIN))  // 1.65 V ref
#define CURRENT_LIMIT_MAX_A (CURRENT_SENSE_SAT_A * 0.98f)
#define VMOT_DIVIDER_RATIO (105.1f / 5.1f)
#define VBUS_GUARD_V 63.0f
#define VBUS_GUARD_FULL_V 66.0f
#define BRAKE_ON_V 64.0f
#define BRAKE_FULL_V 66.0f
#define BRAKE_MAX_DUTY 0.95f
#define BRAKE_PWM_HZ 20000
#define BRAKE_R_OHMS 15.0f
#define BRAKE_R_WATTS 100.0f
#define BRAKE_R_JOULES 300.0f
#define DEMO_MIN_VMOT 15.0f
driver->pwm_frequency = 20000;
driver->dead_zone = 0.02;
driver->voltage_power_supply = 30.0f;   // then readVMOT()
motor->voltage_limit = 4.0;             // MT6701 build
motor->voltage_sensor_align = 1.0;
motor->current_limit = 4.0;
motor->velocity_limit = 20.0;
motor->controller = MotionControlType::velocity;
motor->torque_controller = TorqueControlType::foc_current;
motor->PID_current_q.P = 0.6;  motor->PID_current_q.I = 0.3;  motor->LPF_current_q.Tf = 0.02;  // defaults
motor->PID_velocity.P = 0.3;   motor->PID_velocity.I = 0.1;   motor->PID_velocity.output_ramp = 200; motor->LPF_velocity.Tf = 0.01;

// tuned_gains.txt (2026-05-15)
motor.PID_current_q.P = 0.36;  motor.PID_current_q.I = 1.8;  motor.LPF_current_q.Tf = 0.005;
motor.PID_current_d.P = 0.36;  motor.PID_current_d.I = 1.8;  motor.LPF_current_d.Tf = 0.005;
motor.PID_velocity.P = 0.70779; motor.PID_velocity.I = 3.18506; motor.PID_velocity.output_ramp = 200; motor.LPF_velocity.Tf = 0.01;

// tune.py current-loop tuner: P-only step at P = 1.0, target 0.3 A;
// R = P·(1−G)/G from the DC gain, L = τ63·(R+P); then Kp = ω·L, Ki = ω·R with ω = 200 rad/s,
// halved on overshoot > 20 % or oscillation (up to 5 tries).

// patches/simplefoc_rp2040_current_sense.cpp: adc_set_round_robin(enabled), clkdiv 0,
// FIFO → DMA ring of channelCount × 2 bytes, samples read as latest value; no PWM sync.
```

## Appendix C — reading the board with pcbnew

```python
import pcbnew
b = pcbnew.LoadBoard('sim/work/servodrive_A.kicad_pcb')       # a copy, never the original
origin = pcbnew.VECTOR2I_MM(148, 105)                          # shaft axis
for z in b.Zones():
    for layer in z.GetLayerSet().Seq():
        polys = z.GetFilledPolysList(layer)                    # SHAPE_POLY_SET, already filled
for fp in b.GetFootprints():
    for pad in fp.Pads():
        layers = pad.GetLayerSet().Seq()                       # not pad.GetLayer()
        poly = pad.GetEffectivePolygon()                       # rotated, per-pad angle applied
        drill = pad.GetDrillSizeX()
for t in b.GetTracks():                                        # PCB_TRACK, PCB_VIA, PCB_ARC
    ...
```

Convert with `pcbnew.ToMM()`; subtract the origin so the sim's frame is the tools' frame.
`kicad-cli pcb export gerbers` and `… drill` give an alternative path if a gerber-based
openEMS flow (antmicro's `gerber2ems`) turns out easier for P7.

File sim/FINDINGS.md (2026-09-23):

# servodrive electromagnetic simulation — findings register

Generated by `sim/run.py --phase P9` on 2026-09-12. Evidence names the result key and the figure.

**The IDs are positions in this table, not names.** It is sorted by severity and regenerated whole from `results/*.json`, so adding one finding renumbers every less severe one below it -- an earlier version of this header claimed the opposite, and that was never true of the code. Cite a finding by its evidence key, which is stable, rather than by S-number.

Severity HIGH / MED / LOW / INFO. Status OPEN, DECIDED, HAND-BACK, VERIFIED-OK.

| ID | Sev | Finding | Evidence | Status | Disposition |
|---|---|---|---|---|---|
| S-01 | HIGH | The commutation loop's PCB part is 2.06 nH, 5.3 times geometry.commutation_loop()'s 0.39 nH. VBUS reaches the high-side drain from In2, 0.55 mm below F.Cu, through a 16-via field, not from a plane 0.1 mm away. | `P1.json Q1.solved.L_pcb_nH_at_10MHz; p1_commutation_A.png` | HAND-BACK | Correct geometry.commutation_loop() to the solved value, or replace it with a call that reads P1's result. |
| S-02 | HIGH | Worst-case V_ds is not a board number: it is set by the EG2103's output impedance, which its only obtainable document does not specify. Reading its rated I_O+/I_O- as a resistance at the 12 V drive (40/20 ohm) gives 62.6 V across the whole operating envelope, inside the spec's 68 V criterion. A strong output stage (4/2 ohm) gives 73.9 V, outside it, with a turn-on ring that takes about 31 cycles to fall below 5 % against the criterion's five. Nothing in the sweep reaches the 80 V silicon or the 71.1 V TVS, and the avalanche energy is zero in every run. | `P2.json Q2.driver_impedance, Q2.envelope_sweep; p2_edges.png` | HAND-BACK | Get the real EG2103 datasheet or measure the output impedance on a board; it decides Q2, Q3 and the dV/dt every other answer hangs off. Until then, keep the Q3 snubber footprints. |
| S-03 | HIGH | The off device's V_gs at the die reaches 3.62 V on every high-side turn-on, above the 1.54 V criterion and above the 2.2 V minimum threshold itself. It is almost flat across R_g, drive strength, capacitance corner and driver impedance, because the induced step is the charge divider Q_gd/C_iss and the driver cannot reach the die through 1.6 ohm of internal gate resistance in the few nanoseconds the edge lasts. Measured by difference against a device that cannot conduct: nothing at the typical threshold (-23 nC), and 715 nC / 43 uJ per edge at the datasheet's minimum threshold, where the high-side peak current also rises from 56 to 74 A. | `P2.json Q4.sweep, Q4.cross_conduction` | HAND-BACK | Neither R_g nor a stronger driver moves it. Budget the loss (about 0.86 W per half-bridge at 20 kHz on a bottom-of-distribution part), or change to a device with a smaller Q_gd/C_iss, or provide a negative off-state bias, which this bootstrap driver cannot do without a split rail. |
| S-04 | HIGH | Only 4 of the 16 barrels under each low-side drain (Q2, Q4, Q6) are joined to the switch-node pour on B.Cu; the other 12 are isolated pads in the clearance between the SW and PHASE pours. The busiest carries 7.3 A at the 28.3 A peak, 5.2 A rms against the 2 A a 0.4 mm barrel is worth. | `P3.json Q7.via_array_connectivity` | HAND-BACK | Widen the SW pour on B.Cu to cover the whole array, or move the array, or accept four vias and size them for it. |
| S-05 | HIGH | A decel at the design-point braking torque drives the bus to the TVS breakdown in 0.26 ms and leaves 2 J for a part that survives a few. There is no brake chopper. The firmware's 63-66 V fold-back is the only protection and it reacts in about one 50 us period. | `P6.json Q14.sweep` | OPEN | Decide between a brake resistor, an active clamp, much more bulk, or a documented deceleration limit. |
| S-06 | HIGH | The motor frame is not bonded to board GND by anything on this board -- the four motor mounts are NPTH -- so it follows the switch node: 71 V peak against the 10 V criterion. Bonding it with a long wire makes the voltage worse, because the inductance resonates with the winding-to-frame capacitance. At the driver impedance the datasheet implies, strap 2 nH stays under 10 V at every winding-to-frame capacitance in the sweep; at the strong-driver corner nothing does. | `P2.json Q12.sweep` | OPEN | An enclosure decision: a short low-inductance frame bond, a Y capacitor, or an accepted 71 V common-mode swing on the frame. Measure the motor's winding-to-frame capacitance first; the whole table moves with it. |
| S-07 | MED | An RC snubber of 2.2 ohm and 0.47 nF brings the worst V_ds to 62.7 V for 0.034 W per cell. It is needed only in the strong-driver corner; at the datasheet reading there is nothing to snub. | `P2.json Q3.smallest_that_passes` | HAND-BACK | Add two 0805 footprints per cell across the switch node, and leave them unstuffed unless the driver turns out to be the strong one. |
| S-08 | MED | The standard fix does not work on this part: 22 nF across the gate and source pins moves the die from 3.62 to 2.52 V, because the device's 1.6 ohm of internal gate resistance sits between the pins and the polysilicon. At the pin it looks like it works, which is what a probe would show. | `P2.json Q4.remedy_C_gs` | DECIDED | Do not add gate-source capacitors; they buy the measurement, not the device. |
| S-09 | MED | H3 confirmed: the voltage between the sense taps reaches 159 mV during an edge against 22.6 mV of full-scale signal. | `P2.json Q5.sweep; P1.json Q5.H3` | VERIFIED-OK | No change needed to the filter: the INA241A3's 1 us output hold keeps the error the ADC sees to 27.0 LSB, though 12-14 % of free-running samples are up to a microsecond stale. |
| S-10 | MED | The high-side VBUS arrays are all connected on In2 but share badly: the busiest via carries 2.4 A rms against the 2 A criterion, because the current crowds into the barrels nearest where it arrives. | `P3.json Q7.vbus` | HAND-BACK | More vias, or a spread entry into the array. |
| S-11 | MED | H2: CONFIRMED as a direction, bracketed in size: at 60 V the six 2.2 uF and six 100 nF are worth 5.5-9.7 uF against the 13.2 uF nominal that geometry.interconnect() assumes. No manufacturer DC-bias curve could be retrieved for an unchosen part, so this is a swept bracket, not a measurement. | `P4.json Q13.H2` | HAND-BACK | Use the derated capacitance in geometry.interconnect(), and choose a part whose DC-bias curve is published. |
| S-12 | MED | With the electrolytic bulk the spec originally listed (0.2 ohm ESR) the bus ripple at the drains is over 6 V peak to peak; with polymer hybrids it is under 2 V. | `P4.json Q13_ripple.per_case` | HAND-BACK | Specify polymer-hybrid bulk on board B. |
| S-13 | MED | The Dia 8 x 2.5 mm magnet puts more than the MT6701's 100 mT maximum at the die at the short end of the air-gap tolerance, and an N42 exceeds it at the nominal 1 mm gap as well. The datasheet recommends Dia 6. | `P5.json Q10.magnet` | HAND-BACK | Specify Dia 6 x 2.5 mm, or an N35 with the gap held at or above 1 mm. |
| S-14 | MED | PWM-synchronised sampling cuts the current-loop measurement error from 0.638 to 0.210 A rms and halves the bias. | `P6.json Q8` | HAND-BACK | Pace the ADC from the PWM slice's wrap DREQ, one conversion per phase at the counter's zero. |
| S-15 | MED | The two solvers model a plated via differently, and neither models it as it is. fasthenry/mesher.add_barrel() uses a square bar of the same cross-sectional AREA as the plating -- right for resistance, and for a 0.4 mm hole its geometric mean distance is 0.082 mm against the tube's 0.225 mm, so each barrel comes out 0.206 nH instead of 0.094 nH, 2.2 times too inductive. The FDTD model uses a solid rod of the PAD diameter, 0.058 nH, too fat. The truth is between them and the commutation loop runs through sixteen of them. Re-solving the 0.35 mm point with every barrel at its real plated diameter moves the loop from 1.76 to 2.01 nH. | `P7.json Q1_crosscheck.barrel_model_sensitivity` | HAND-BACK | Give add_barrel() a bar of the same geometric mean distance as the plated tube and scale its conductivity to keep the copper area, so R and L are both right; then re-run P1 Q1. |
| S-16 | LOW | Phase current moves the reported angle by 0.090 deg peak (4.1 LSB) against the 0.05 deg criterion. It is the three motor leads that do it, not the board copper, whose fields cancel on the shaft axis. | `P5.json Q10.angle_error` | HAND-BACK | Twist or bundle the three leads where they leave the board, or compensate in firmware -- the error moves with the current and is therefore predictable. |
| S-17 | LOW | The software dead_zone of 0.02 costs 0.76 % of torque and leaves the distortion essentially unchanged; the EG2103's own 560 ns already dominates. | `P6.json Q9.sweep` | HAND-BACK | Set dead_zone = 0 and rely on the driver's interlock. |
| S-18 | INFO | dV/dt at the switch node is 6-52 kV/us across the driver-impedance bracket, against the design point's 1.2 kV/us. Every estimate downstream of the edge rate moves with it, including the common-mode current Q12 computes. | `P2.json Q4.sweep dVdt_switch_node_kV_per_us` | OPEN | Recompute the enclosure's common-mode budget once the driver's output impedance is known. |
| S-19 | INFO | The spec's Q5 criterion -- settle to +-1 LSB within 500 ns -- cannot be met by the chosen amplifier, whose own common-mode hold is 1 us. The criterion is the wrong shape for the part. | `models/ina241a3.json pwm_hold; SBOSA30D sec.7.3.1.1` | DECIDED | Replace the criterion with a bound on the error in LSB. |
| S-20 | INFO | The sense chain's DC accuracy is good: tap to tap is 0.8301 mohm of which 3.6 % is copper, and the total TCR is 0.019 %/K -- both inside the criteria. | `P3.json Q6.per_cell.A` | VERIFIED-OK | No change. |
| S-21 | INFO | The driver's 560 ns minimum pulse makes duties below 2.40 % and above the mirror of that unreachable at 20 kHz. | `P6.json Q9.min_duty_reachable` | DECIDED | Clamp the modulation index in firmware so the loop never commands an unreachable duty. |
| S-22 | INFO | The first run of this phase reported 3.82 nH against L1 and called it a disagreement. It was neither, and the largest error was not in the mesh: the conducting FETs were cylinders of 0.25 mm radius about an axis in F.Cu, which is 0.1525 mm above In1, so each rod cut through about 1 mm2 of the ground plane and the high-side one shorted VBUS to GND at the drain -- the current never reached In2 or the via field. On top of that the run was stopped at 1.4 times its own excitation length with the energy still at -2 dB, it was compared with L_eff (all four capacitors in parallel) when it drives one, and its 127 "dropped primitives" were via pads the barrel cylinders already provide. With the device modelled as a strip inside its own layer and the energy decayed to -43.75 dB on a mesh snapped to the copper, openEMS gives 3.04 nH for that one capacitor's loop against FastHenry's 2.68 nH, 9 % apart. | `P7.json Q1_crosscheck; p7_crosscheck.png` | VERIFIED-OK | None. |
| S-23 | INFO | SPEC.md sec.5.4 expects 17.4 nH for the straight-wire known-answer test, but its own formula with l = 20 mm and d = 1 mm gives 14.53 nH, which is what FastHenry returns to 0.03 %. The expected value in the spec is wrong, not the solver. | `P0.json known_answer_tests.fasthenry_wire` | DECIDED | Correct the expected value in SPEC.md. |
| S-24 | INFO | The L1/L2 cross-check passes once both models are right. On the single port they can be compared on, openEMS gives 2.91 nH -- its own device strip de-embedded, 3.04 nH raw -- against FastHenry's 2.68 nH, 9 % apart against the spec's 25 % gate. The full-wave model also returns what the PEEC one cannot see: the loop carries about 52 pF of its own capacitance and self-resonates near 399 MHz. FastHenry's own grid sweep had not been run out either: L_eff falls from 2.35 nH at 1.8 mm to 1.98 nH at 0.75 mm and settles there, 1.6 % on the last refinement, so the loop this register quotes as 2.06 nH is 1.98 nH converged. | `P7.json Q1_crosscheck.mesh_convergence; p7_crosscheck.png` | VERIFIED-OK | Re-run P1's frequency sweep at the finer grid so the number S-01 quotes comes from the converged end of its own series. |

## Hypotheses

| | Claim | Verdict |
|---|---|---|
| H1 | the commutation loop is bigger than 0.39 nH, expected 0.8-1.5 nH for the PCB part and about 2.5-3 nH total | CONFIRMED, and by more than the hypothesis expected: the PCB part is 2.06 nH, 5.3 times geometry.commutation_loop()'s 0.39 nH, because VBUS reaches the high-side drain from In2 (0.55 mm below F.Cu) through a 16-via field, not from a plane 0.1 mm away. |
| H2 | the DC-link ceramics are not 13 uF at 60 V; a 100 V X7R 1206 typically keeps 40-60 % of its value at 60 % of rating | CONFIRMED as a direction, bracketed in size: at 60 V the six 2.2 uF and six 100 nF are worth 5.5-9.7 uF against the 13.2 uF nominal that geometry.interconnect() assumes. No manufacturer DC-bias curve could be retrieved for an unchosen part, so this is a swept bracket, not a measurement. |
| H3 | the shunt's ESL dominates the sense signal during edges: 0.2-0.5 nH at 0.87 A/ns is 170-430 mV against 22.6 mV of signal | CONFIRMED |
| H4 | the two sense taps are not symmetric, so a common-mode step becomes a differential one | capacitance asymmetry solved with FastCap: asymmetry_sw_pF -0.064 pF, asymmetry_phase_pF +0.020 pF, asymmetry_gnd_pF -0.616 pF |

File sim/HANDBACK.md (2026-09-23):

# servodrive — hand-back list

Generated 2026-09-12 from `sim/results/*.json`. Nothing in `sim/` applies any of this: it is for a human to decide from.

Every placement change means `python3 tools/gen_boards.py --force` and then `python3 tools/route.py --rounds 4 --loose`, **which discards the routing**. The constants that only change a number in the model do not.

## The commutation-loop model is 5 times out

- **Where:** `tools/geometry.py: commutation_loop()`
- **Proposed:** L_pcb = 2.06 nH (solved, all four DC-link capacitors in parallel) rather than mu0*h*l/w = 0.387 nH; total 3.35–3.19 nH. Use 1.98 nH: the same model at the converged end of its own grid sweep, 4 % below the figure above. Q11 puts the single port both solvers can be compared on at 2.68–2.91 nH
- **Because:** VBUS reaches the high-side drain from In2 through a 16-via field, not from a plane 0.1 mm away (P1, H1); its size is settled by the grid sweep and cross-checked full wave (P7)
- **Effect:** every derived number moves: overshoot, ring frequency, the snubber decision
- **Re-run:** nothing on the board; `python3 tools/geometry.py` to refresh the figures

## Pin down the EG2103's output impedance

- **Where:** `models/eg2103.json: I_source, I_sink and the condition they are measured at`
- **Proposed:** get the real datasheet, or measure the gate edge into a known capacitance on a built board, and record the condition beside the number
- **Because:** the only obtainable EG2103 document gives I_O+/I_O- without the test condition, so the model brackets it 40/20 ohm to 4/2 ohm (P2, Q2)
- **Effect:** it is the difference between 62.6 V of V_ds (inside the 68 V criterion, no ring, no snubber) and 73.9 V (outside it, a 145 MHz ring, and a snubber); every dV/dt-sensitive answer in the report moves with it
- **Re-run:** nothing on the board; re-run P2 and P9

## Add snubber footprints, unstuffed

- **Where:** `tools/placement.py (two 0805 per cell), tools/schematic.py`
- **Proposed:** R = 2.2 ohm, C = 0.47 nF from SW_x to GND, as close to the low-side source pads as the cell allows; fitted only if the driver turns out to be the strong one
- **Because:** worst-case V_ds is 73.9 V on 80 V silicon in the strong-driver corner, and inside the criterion in the other (P2, Q2)
- **Effect:** worst-case V_ds falls to 62.7 V; 0.034 W per cell at 20 kHz
- **Re-run:** gen_boards.py --force, then route.py — discards the routing

## Budget for Miller cross-conduction, or change the device

- **Where:** `tools/geometry.py: the switching-loss term; or the FET choice itself`
- **Proposed:** either carry 0.86 W per half-bridge of extra loss and a 74 A peak in the loss and SOA budgets, or pick a device with a smaller Q_gd/C_iss
- **Because:** the off device's V_gs at the die reaches 3.62 V, above both the 1.54 V criterion and the 2.2 V minimum threshold, on every high-side turn-on, and neither R_g nor a stronger driver nor a gate-source capacitor moves it (P2, Q4)
- **Effect:** at the typical threshold there is no cross-conduction at all (-23 nC); at the datasheet minimum there is 715 nC per edge
- **Re-run:** nothing on the board unless the device changes

## Twelve of sixteen low-side drain vias are islands

- **Where:** `tools/fanout.py / the B.Cu zone outlines for SW_x`
- **Proposed:** extend the SW_x pour on B.Cu so it covers the whole 4 x 4 array, or move the array inboard of the PHASE pour's edge
- **Because:** solved via currents in P3, Q7: the busiest carries 5.2 A rms against 2 A
- **Effect:** the phase current would cross to B.Cu through sixteen barrels instead of four; per-via current falls by about four times
- **Re-run:** gen_boards.py --force, then route.py — discards the routing

## The high-side arrays share badly

- **Where:** `tools/geometry.py: FET_VIA_N`
- **Proposed:** raise from 16, or spread the entry into the array; the busiest via carries 2.4 A rms
- **Because:** P3, Q7
- **Effect:** per-via current falls in proportion
- **Re-run:** gen_boards.py --force, then route.py — discards the routing

## The DC-link ceramics are worth about half their marking

- **Where:** `tools/geometry.py: interconnect(), the 13 uF assumption`
- **Proposed:** use 7.0 uF at 60 V (bracket 5.5–9.7) instead of 13.2
- **Because:** H2, P4
- **Effect:** the ripple split shifts and more of it crosses the header
- **Re-run:** nothing on the board

## Board B's bulk must be polymer hybrid

- **Where:** `the board B specification (spec.html §8)`
- **Proposed:** 4 x 100 uF polymer hybrid, ESR 20–40 mohm each; not 3 x 100 uF electrolytic at 0.2 ohm
- **Because:** P4, Q13 ripple table
- **Effect:** bus ripple at the drains falls from over 6 V p-p to under 2
- **Re-run:** nothing on board A

## The magnet is too strong at the short end of the gap

- **Where:** `tools/geometry.py: MAGNET_D (and the magnet's grade)`
- **Proposed:** Dia 6 x 2.5 mm, as the MT6701 datasheet recommends, or hold the air gap at or above 1 mm with an N35
- **Because:** P5, Q10 magnet table
- **Effect:** keeps the field at the die inside the part's 20–100 mT window over the whole tolerance
- **Re-run:** MAGNET_D changes the keepout, so gen_boards.py --force and route.py — discards the routing

## Bundle the three motor leads

- **Where:** `assembly instruction, not a board change`
- **Proposed:** twist or bundle the three phase leads for the first 50 mm after they leave the lead pads
- **Because:** P5, Q10
- **Effect:** removes most of the 0.090 deg current-dependent angle error; the board copper's own field already cancels on the shaft axis
- **Re-run:** nothing

## Pace the ADC from the PWM

- **Where:** `firmware: patches/simplefoc_rp2040_current_sense.cpp`
- **Proposed:** a DMA channel paced by the PWM slice's wrap DREQ writing START_ONCE to ADC_CS, one conversion per phase at the counter's zero, instead of free-running round-robin
- **Because:** P6, Q8
- **Effect:** current-loop measurement error falls from 0.638 to 0.210 A rms and the bias halves
- **Re-run:** firmware only

## Set dead_zone to zero

- **Where:** `firmware: driver->dead_zone`
- **Proposed:** 0.0, relying on the EG2103's own 560 ns interlock
- **Because:** P6, Q9
- **Effect:** recovers 0.76 % of torque and changes the distortion hardly at all
- **Re-run:** firmware only

## Clamp the modulation index

- **Where:** `firmware: the duty the driver is given`
- **Proposed:** never command a duty below 2.40 % or above its mirror
- **Because:** P6, Q9
- **Effect:** keeps the loop out of the region where the driver silently passes no pulse
- **Re-run:** firmware only

## Decide how the motor frame is bonded

- **Where:** `the enclosure, not the board -- the four motor mounts are NPTH and cannot be changed into a bond without copper round them`
- **Proposed:** the sweep's best option is ycap 4.7 nF at 2 V of frame swing
- **Because:** P2, Q12
- **Effect:** today the frame follows the switch node to about 71 V peak; a long bonding wire makes it worse, not better, because its inductance resonates with the winding-to-frame capacitance
- **Re-run:** nothing on board A unless a Y capacitor is wanted on it

## Decide what happens on a decel

- **Where:** `spec.html §11 questions 3 and 7 — an open design question`
- **Proposed:** a brake resistor, an active clamp, a much larger bulk, or a documented deceleration limit
- **Because:** P6, Q14
- **Effect:** today the only protection is a software fold-back and two TVSs that would be asked to take tens of joules
- **Re-run:** board B and/or firmware

## Correct the spec's own known-answer value

- **Where:** `sim/SPEC.md §5.4, the FastHenry straight-wire row`
- **Proposed:** 14.53 nH, not 17.4 nH, for l = 20 mm and d = 1 mm
- **Because:** P0 known-answer tests
- **Effect:** the test passes as written once the expected value is right
- **Re-run:** nothing

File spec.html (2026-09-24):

← servodrive

# Specification

Draft 0.6

A round, motor-mounted servodrive: a Ø65 mm two-board stack with the magnetic rotary encoder on the shaft axis. 60 V bus on 80 V silicon, three phases, RP2350A. Derived from rp2350-motor-controller, which supplies the encoder circuit, the power-stage part choices, and — more usefully — a review register of everything that went wrong there.

2026-09-07, revised 2026-09-22 · every number below is computed by tools/geometry.py and the floorplan by tools/placement.py · LCSC stock figures checked 2026-09-07 and perishable

## 1 · What it is

Two identical-diameter round boards stacked on the back of a motor.

### Board A — motor board

Bolts to the motor through the encoder's four-hole pattern.

- MT6701 magnetic rotary encoder on the shaft axis, on the motor-facing side
- Three half-bridges — 6 × 80 V MOSFET, 3 × EG2103 gate driver
- Two inline phase-current shunts and their amplifiers
- RP2350A, crystal, QSPI flash, 3.3 V LDO
- High-frequency DC-link ceramics, at the bridge
- Three phase pads at the perimeter, on the motor-facing side — the leads come off the motor on that side, and the outward perimeter is spoken for

### Board B — power / IO board

Mounts on six perimeter standoffs above board A.

- Bus input on an XT30, 12–60 V — or USB-PD instead of it, never both (§7); TVS, bulk capacitance
- VMOT → 12 V gate rail and VMOT → 5 V logic rail
- USB-C with full PD — a 20 V contract feeds VMOT and runs the motor
- Full-duplex RS-485, two ports, chained through
- Status LED, debug header, BOOTSEL

The split is drawn where it costs least. Everything with a fast di/dt loop — gate loops and commutation loops both — stays on board A. What crosses the interconnect is a DC bus, three regulated rails and a handful of slow signals.

What the split costs — measured, not assumed. Draft 0.2 asserted that with ≈13 µF of ceramic on board A the interconnect would see average bus current rather than ripple, and asked for a loop-inductance estimate before layout. Both halves have now been done, in geometry.commutation_loop() and geometry.interconnect(), and they do not agree with each other.

- The loop is fine. With the In1 ground plane 0.1 mm below F.Cu the PCB contributes 0.39 nH; two PowerPAK packages and the 1210 ESL bring it to 2.0 nH. At 0.87 A/ns that is 1.7 V of overshoot — a 61.7 V peak on 80 V silicon. The ceramics do their job and the TVS never conducts in normal operation.
- The interconnect is not. At 20 A RMS per phase the DC link carries 21.2 A of bus current plus 12.4 A RMS of ripple, and at 20 kHz the ceramics on board A are a 0.61 Ω path against the bulk's 0.2 Ω, so three quarters of that ripple crosses the header anyway: 23.2 A RMS. A 2×8 at 3 A/pin is 24 A. Eight hundred milliamps is not a continuous rating, so the power link is two 2×5 and 30 A — see §8.

The ceramic budget itself stands: it is the megahertz content that matters locally, and above about 600 kHz the ceramics own it.

## 2 · Mechanical

Plan view of board A: 65 mm circle, four M3 motor mount holes at 25 mm and 19 mm spacings around a central MT6701, six M2.5 perimeter holes on a 59 mm bolt circle, three phase cells at 120 degrees i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

Board A, drawn from the placement itself rather than from an intention: tools/geometry.py reads the same coordinates gen_boards.py writes into the KiCad file. Solid courtyards are on the outward face, dashed ones on the motor-facing face. The three phase cells sit at 60°/180°/300° so all three commutation loops are the same shape; the three wedges between them carry the interconnect and the CPU; the gold arcs at the perimeter are bare copper for the heatsink ring, and are the reason every part stops at R 29.2. Nothing but the encoder and the motor screws lives inside Ø32.

Geometry — single source of truth is tools/geometry.py
Item | Value | Where it comes from
Board diameter, both boards | Ø65.0 mm | Set 2026-09-07
Motor mount | 4 × Ø3.2 (M3) at (±12.5, 0) and (0, ±9.5) | Inherited verbatim from hardware/encoder H1–H4
Encoder centre | (0, 0) — coincides with the shaft axis | MT6701 sensing centre
Central keepout | R < 16 mm, both faces | Screw heads + magnet clearance
Sections | Three phase cells of 60° at 30/90/150°, adjacent, then three 60° wedges at 210/270/330° | Grouped rather than alternating, and narrowed — see below
Board-B mounting | 6 × M2.5 on a Ø59 bolt circle, on the six section boundaries: 0, 60, 120, 180, 240, 300° | Every section gets one at each edge — and at 60/60 that is an even circle again
Phase pads | 3 arcs, R 28.1–31.3 over 14°, 23 mm² each, at 30°/90°/150°, on B.Cu | 14 AWG motor leads. An arc, because a straight pad this wide at this radius puts its corners off the board
Heatsink land | 3 arcs, R 29.2–31.5 over 48°, plus six Ø4.8 mm bosses = 250 mm² of bare copper | §4 — the joint a heatsink would clamp, 0.33 K/W; kept although no fins are planned
Parts placed, board A | 124 by the floorplan — 69 outward, 55 motor-facing, 10 DNP — and 12 generated (lands, lead pads, bosses) | tools/placement.py
Netlist, board A | 136 components, 87 nets, 425 connections | tools/schematic.py, checked against the placement both ways
Usable annulus | R 16 → 31.5 = 2313 mm² per side | Computed
Board A stackup | 6 layer, 2 oz outer / 1 oz inner, 1.6 mm, 0.1 mm F.Cu→In1 prepreg | Same as the sister board, except the prepreg, which is what §1's 0.39 nH rests on
Board B stackup | 4 layer, 2 oz outer, 1.6 mm | No dense routing; 4 is enough
Standoff, motor face → board A | 10.75 mm | Derived: 5.0 shaft + 2.5 magnet + 1.5 air gap + 1.75 MT6701 body
Standoff, board A → board B | 11.0 mm | Board A parts + mated interconnect height
Total above the motor rear face | 36.0 mm | Connectors and bulk cans included

The three phase cells are adjacent, and the three wedges with them. Draft 0.3 alternated them — phase, wedge, phase, wedge — which put the RP2350A with a half-bridge 25° away on each side. Grouping costs nothing inside a cell (the width is unchanged at 70°) and buys three things:

- The CPU moves to the middle of the wedge group, as far from every switching node as a round board allows.
- The three motor leads leave together, so one bundle leaves the enclosure through one hole instead of three.
- The DC bus feeds one contiguous 210° block from the power link at its edge, rather than reaching around the board past the CPU.

The six M2.5 sit on the six section boundaries, so every section has a bolt at each edge and every phase cell's heatsink land runs the full width between its own two. At 70/50 that cost the even spacing; at 60/60 it does not, and the bolt circle is regular again.

And the cells came in from 70° to 60°, using the channel interior to the screws. A phase cell is short of angle, not of area, and angle costs radius: a millimetre of arc at R 20 is 2.9°, the same millimetre at R 29.5 is 1.9°. The cell was 70° because small parts sat at small radius — a 1 µF 0805 beside the gate driver was taking 30° on its own, while both MOSFETs together needed 18.

The six boss pads sit on R 26.9–32.2, and between them that band is empty: the heatsink land owns it on the outward face, and on the motor-facing face nothing but the lead pads wants it. So everything without a reason to be somewhere in particular now lives there at R 29.3 — the bootstrap diode (only its capacitor has to be at VB and VS), the DC-link 100 n, both input pulls, and each phase's clamp diode, which ends up beside its own lead pad. The DC-link bulk ceramic moved to its own row at R 26.8, as far out as the land allows.

That held for the utility wedges and not for the phase cells. Routing found that a part in a phase cell's channel can be connected only if its nets are GND or the phase output — the phase-output pour owns B.Cu beneath it, the heatsink land owns F.Cu above it, and the bosses cut the outer ring into six arcs. Five of the six went back into the cell and the cells were widened to 68° to take them. The clamp diode stayed, because its nets are exactly the two that work. §10b has the measurement.

| 70° cells | all in the channel | now
Phase cell | 70° | 60° | 68°
Utility wedge | 50° | 60° | 52°
Phase group | 210° | 180° | 204°
Bolt spacing | 70/70/70/50/50/50° | 60°, even | 68/68/68/52/52/52°
In the channel, per cell | — | 6 parts | 1, the clamp diode
Heatsink land | 286 mm² | 250 mm² | 279 mm²

Three consolidations paid for it: the per-driver 1 µF VCC bulk became one 4.7 µF at the power link (three of them on one 0.1 A rail was two too many), the lead pad narrowed from ±8.5° to ±7° — 23 mm², still ample for a 14 AWG lead — and the row packer learned to dodge parts in other rows, because two rows that overlap radially and sit at different angles can collide and a packer that only looks at its own row walks straight into them.

Area is not the constraint. The sister board fits a four-bridge stage, a twelve-pin switched encoder port, isolated CAN and USB-PD into roughly 4400 mm² of courtyard across two sides. This design has four usable sides of 2313 mm² and far less to put on them. That buys the right to keep thermally generous packages instead of chasing the shrinks in the sister project's F-47 — take the small parts where they are also better parts, not merely smaller ones.

Side view of the stack: motor rear face, encoder air gap and standoff, board A, interconnect gap, board B, connectors.

Stack elevation. The standoff under board A is not a free choice — it is whatever the shaft, the magnet holder, the MT6701's working air gap and the SO-8 body add up to, and it lands at 10.75 mm on the placeholder numbers. Change the shaft height in tools/geometry.py once the motor is known and every dimension here follows.

## 3 · Power stage

Electrical design point
Bus voltage | 60 V nominal, 12 V minimum (decided 2026-09-22), 80 V silicon throughout, TVS breakdown 71–79 V
Phase current | 20 A RMS per phase — the figure everything is sized to, and since 2026-09-22 a burst figure rather than a continuous rating (§4) — 28.3 A peak, ±32 A of sense. Draft 0.2 used “20 A” for the RMS figure in §4 and for an instantaneous one in §5; they differ by √2 and the sense chain lost. One number now.
Switching frequency | 20 kHz nominal (the number every estimate below is quoted at)
Topology | Three independent half-bridges, software dead time, inline phase-current sense

Parts, and why each one differs from the sister board
Function | Part | Rationale
MOSFET, 6 × | BSC030N08NS5, PowerPAK SO-8 | Unchanged. 80 V, 2.6/3.4 mΩ at VGS = 10 V, 100% avalanche tested, 27k in stock at LCSC. Driven properly this time — see the row below.
Gate driver, 3 × | EG2103, SOP-8 | Changed. The sister board's EG3113 is unbuyable — 9 in stock, minimum purchase 25 (their F-40, which blocks its ordering). The obvious like-for-like replacement, EG2131, turns out to be also out of stock. EG2103 is the same EG Micro family and the same logic convention, 2,225 in stock, MOQ 5, $0.19 @100: 600 V, VCC 10–20 V, interlock plus 560 ns internal dead time, HIN active-high with a 200 k pull-down, LIN active-low with a 200 k pull-up. It needs the 12 V rail, and that is the point. What it gives up is drive strength — ±0.3/0.6 A against EG3113's 2/2.5 A — costed in §4.
Gate rail | 12 V, its own buck on board B | Changed. This is the single largest improvement available and it is quantified in the sister project's F-41: driving a 10 V-rated FET from a 5.04 V rail costs ~2 W per bridge of switching loss and ~15% on RDS(on). See §4.
Gate network | 2.2 Ω + 10 k G–S, PNP booster DNP | Changed, because the driver is now the limit rather than the resistor. EG2103 saturates at 0.3 A, and reaching that from a 12 V rail needs Rg ≈ 28 Ω — so below about 28 Ω the resistor buys no speed at all and only adds turn-off delay against the 0.6 A sink. 2.2 Ω is therefore for gate-loop damping, not for edge shaping. Footprints kept for the sister board's PNP turn-off booster (their Q1 + D6/D7), which is the proven way to buy the turn-off edge back if §4's switching term proves binding on the bench.
Current sense, 2 × | INA241A3, TSOT-23-8, 50 V/V | Changed. Higher gain lets the shunt shrink. Inline, not low side, so torque is measurable at standstill and at any duty cycle. The package is TSOT-23-8 (the DDF suffix), not the SOT-23-8 draft 0.2 wrote; that is what is placed on board A. A third footprint sits on phase C, DNP — there is no fourth ADC channel for it. And the grade is A3. INA240 numbers its gains A1 = 20, A2 = 50; INA241 numbers them A1 = 10, A2 = 20, A3 = 50. Draft 0.2 carried the INA240 mapping across and asked for a 20 V/V part to do a 50 V/V job — table 4-1 of the INA241A datasheet.
Shunts, 2 × | 1.0 mΩ (2 × 2 mΩ 2010) | Changed again, and this one is a correction rather than an improvement. Draft 0.2's 1.6 mΩ was chosen to reproduce the sister board's 80 mV/A so firmware constants would carry across. It gives ±20.6 A of full scale, and the design point peaks at 28.3 A: the chain would have clipped on every cycle above 14.6 A RMS. 1.0 mΩ × 50 V/V = 50 mV/A → ±29.0 A worst case, 2.5% over the peak, and costs 0.80 W instead of 1.28 W — the 0.8 mΩ pair this row carried until 2026-09-24 has no stocked 1.6 mΩ 2010 to build it from. Phase C gets the same two footprints as 0 Ω links so all three phases match. See §5.
Phase TVS, 3 × | TPSMF4L64A, SOD-123FL | Same 64 V standoff / 400 W as SMAJ64A (their F-09 fix) in a much smaller package — one of the F-47 swaps that is worth taking.
DC-link ceramic | 6 × 2.2 µF 100 V 1206 + 6 × 100 n | New requirement created by putting the bulk on board B. Two of each per cell, flanking the FET pair tangentially inside the commutation loop. §1 now has the measurement that justifies them: 0.39 nH of PCB loop, 1.7 V of overshoot.

Input pulls, 6 ×

4.7 k on every HIN and LIN

New, and not optional. Two errata meet on this pin. EG2103's LIN is active-low with an internal 200 k pull-up; RP2350's GPIOs leave reset as inputs with a ~60 k pull-down, and erratum E9 can latch a Bank 0 input near 2.1–2.2 V. The divider of those two lands LIN around 1.2 V — above VIL 1.0 and below VIH 2.5, which is the one place a gate driver input must never sit. 4.7 k to GND on both HIN and LIN makes the reset state a property of this board instead of two other people's errata, and ≤9 k is also the documented E9 workaround. To GND on both is the brake-on-reset decision of 2026-09-22 (the box below); until then LIN went to +3V3, for a coast. They sit on the driver's logic side, one via each.
RC snubber, 3 × | 2.2 Ω + 470 pF C0G 100 V, 0603, DNP | New, footprints only. The simulation's answer to the one corner that fails: if the EG2103's output stage is the strong one, the turn-on ring reaches 73.9 V of Vds; this across the switch node takes it to 62.7 V for 0.034 W per cell (sim P2, Q3). Fitted only if the driver measures strong. On the back under the high-side FET, the resistor's pad on the switch-node pour and the capacitor's on a ground via, their middle node a pour of its own. 0603 rather than the 0805 the simulation proposed, because an 0805 pair does not fit between the sense tap and the shunt; the ratings do not need 0805.

Every changed row above is a sourcing risk until checked. The sister project's F-40 is precisely the failure of not doing this: a design that cannot be ordered because one part has nine in stock. Before any of these reach a schematic symbol, confirm LCSC stock depth and minimum buy for INA241A2 — F-47 verified the A1 in SOT-23-8, not the 50 V/V grade, which is INA241A2IDDFR in TSOT-23-8; INA240A2PWR (C129949) is in stock as a fallback but is TSSOP-8 and only ±80 V common mode against INA241's ±110 V, so it is a different footprint and less margin on a 60 V phase node — 2.0 mΩ 2010 shunts at 1% or better, TPSMF4L64A, LMR38010, and the ripple-rated bulk §8 now needs. F-47 already notes that ISO1044 "is absent from the JLC in-stock listing today" despite being the recommended swap; assume nothing.

Checked 2026-09-07, and the results are why this box exists: EG2103 C480654 — 2,225, MOQ 5, $0.19, but only 0.3/0.6 A drive; FD2103S C5187182 — out of stock, and it was the cheapest hit; EG2131 C193777 — not available; UCC27282DR C2867844 — 1,227, $1.99; NCP5183DR2G C904511 — 2,883, MOQ 1, $0.92, but 4.3 A and no interlock. EG2103 chosen: the interlock and the 560 ns dead time are worth more here than the edge rate. Three of the five first-choice parts were unbuyable or overpriced. The 40 V-class question does not arise here, but no confirmed high-stock 80 V alternative to BSC030N08NS5 was sought — it has 27k in stock and stays.

Fail-safe by construction — the die coasts, and the board now brakes. Draft 0.2 left this open because the sources disagreed. EG2103's own datasheet (V1.0, 2018‑11‑11) settles it, and the interesting part is that it contradicts itself.

- Its truth table is unambiguous: HIN = LIN = 0 turns the low side on, HIN = LIN = 1 turns the high side on, and any disagreement turns both off. LIN is active-low, as §6 assumed.
- Its block diagram draws 200 k from an internal +5 V into LIN, and 200 k from HIN to ground.
- Its parameter table agrees: Iin(L) is specified as −10 µA at Vin = 0 V. Current flowing out of an input held low is a pull-up, and it is a guaranteed number rather than a drawing. Quiescent current is also specified with the inputs floating, which is not how you characterise a part whose floating state turns a MOSFET on.
- Its prose, in §2, says LIN has a 200 k pull-down — and then finishes the same sentence by claiming floating inputs turn both MOSFETs off, which is only true if it is a pull-up. It is a copy-paste of the HIN clause. EG Micro's website has the corrected wording; LCSC's summary repeats the typo.
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

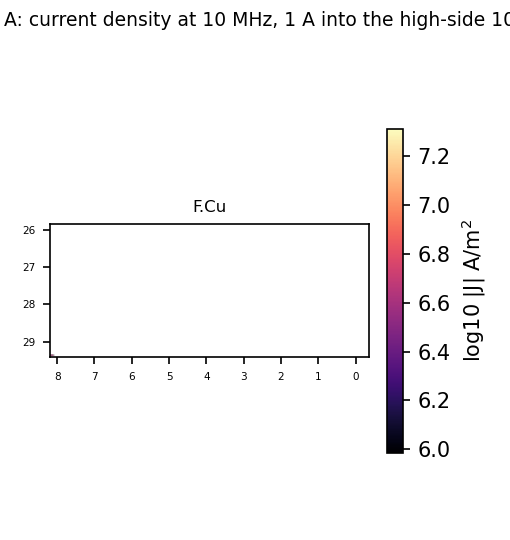
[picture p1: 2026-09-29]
sim/report/img/s/p1_current_A.png

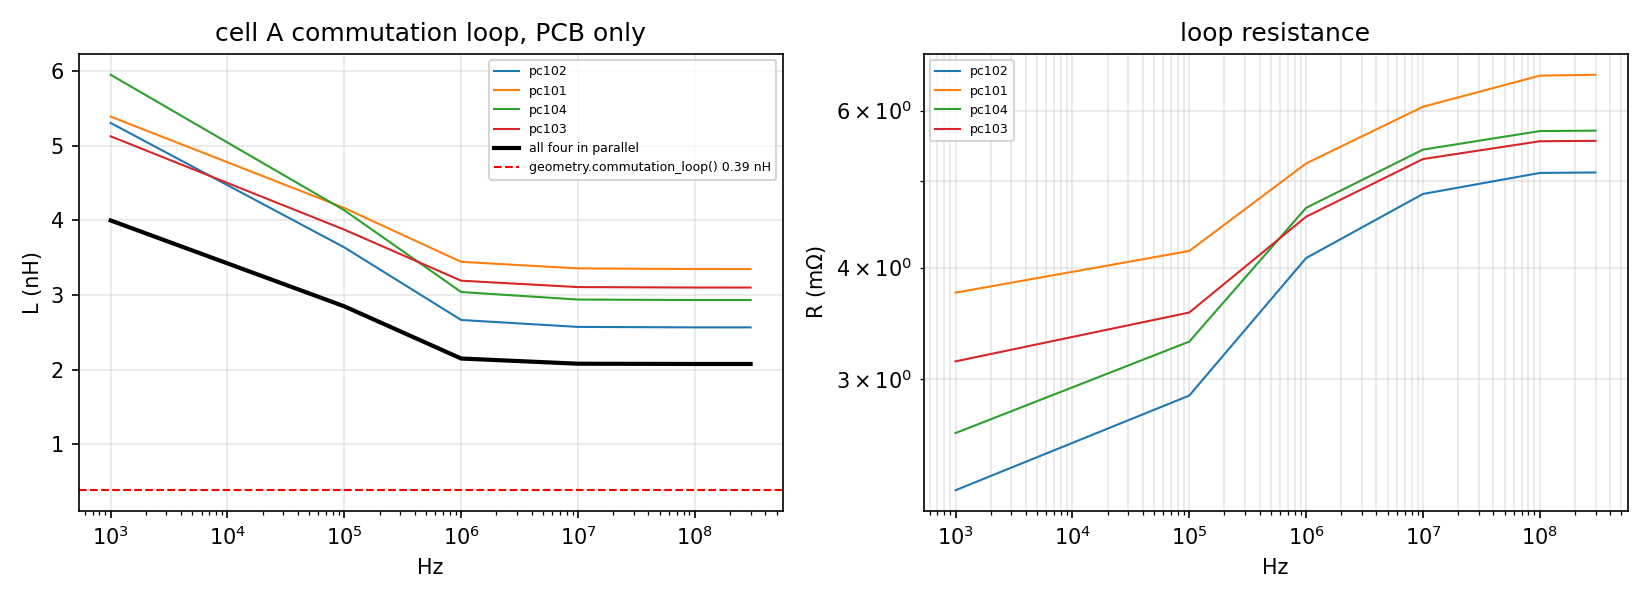
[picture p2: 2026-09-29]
sim/report/img/s/p1_commutation_A.png

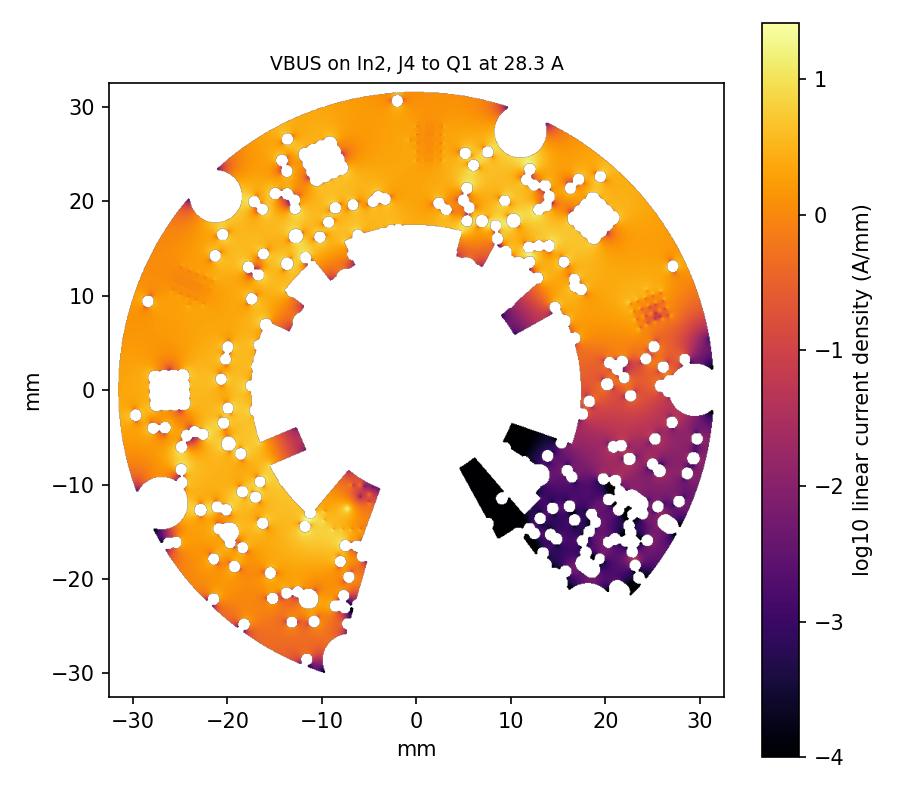
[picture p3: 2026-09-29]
sim/report/img/s/p3_J_vbus_In2.png

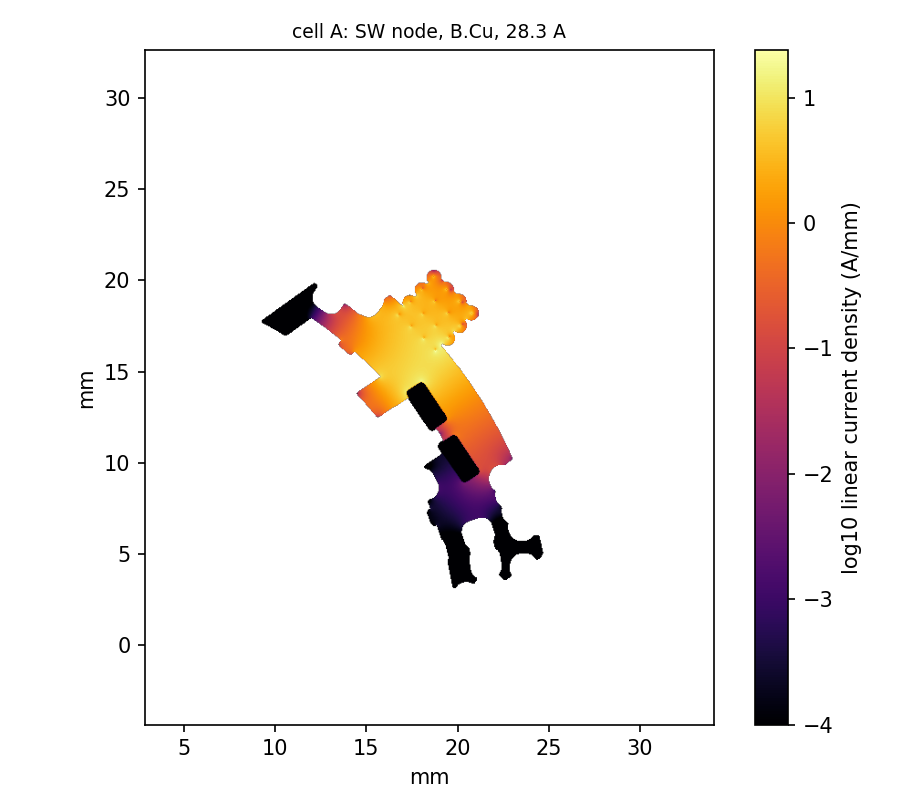
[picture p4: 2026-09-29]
sim/report/img/s/p3_J_sw_A_BCu.png

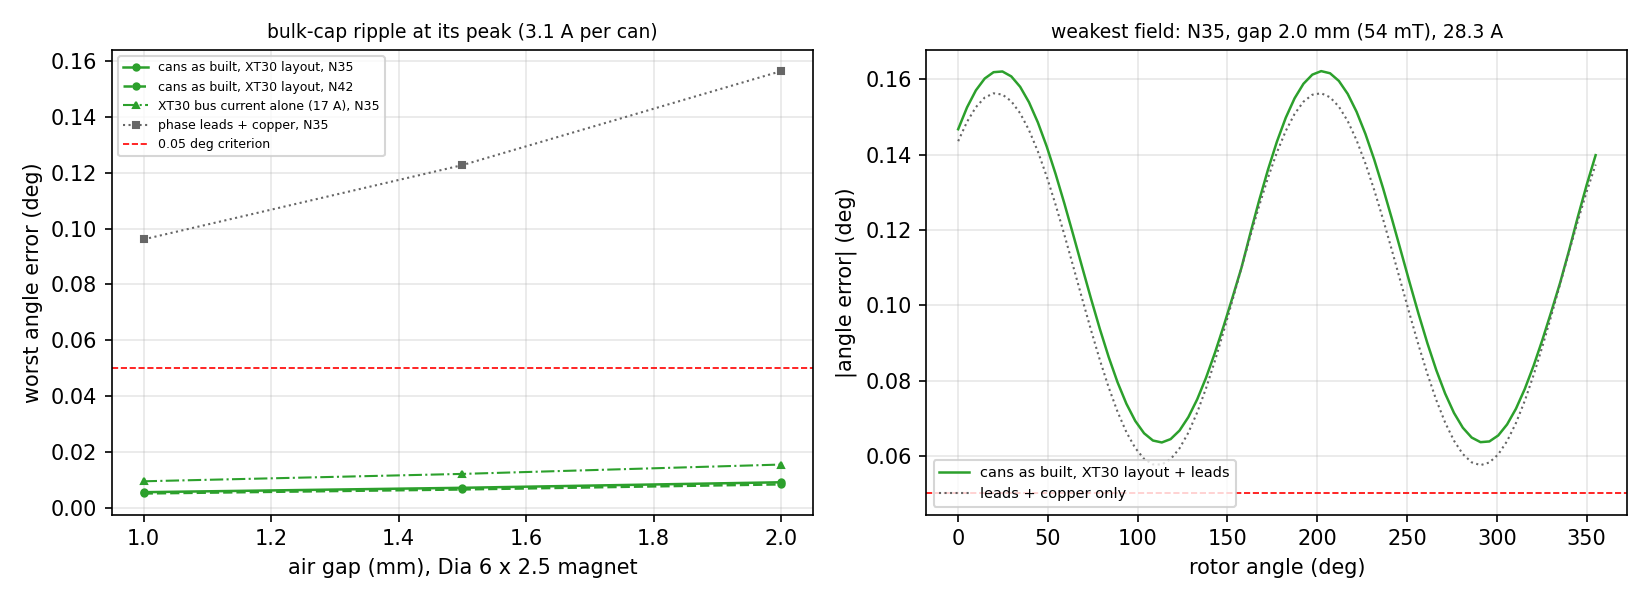
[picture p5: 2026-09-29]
sim/report/img/s/p5s_board_s.png

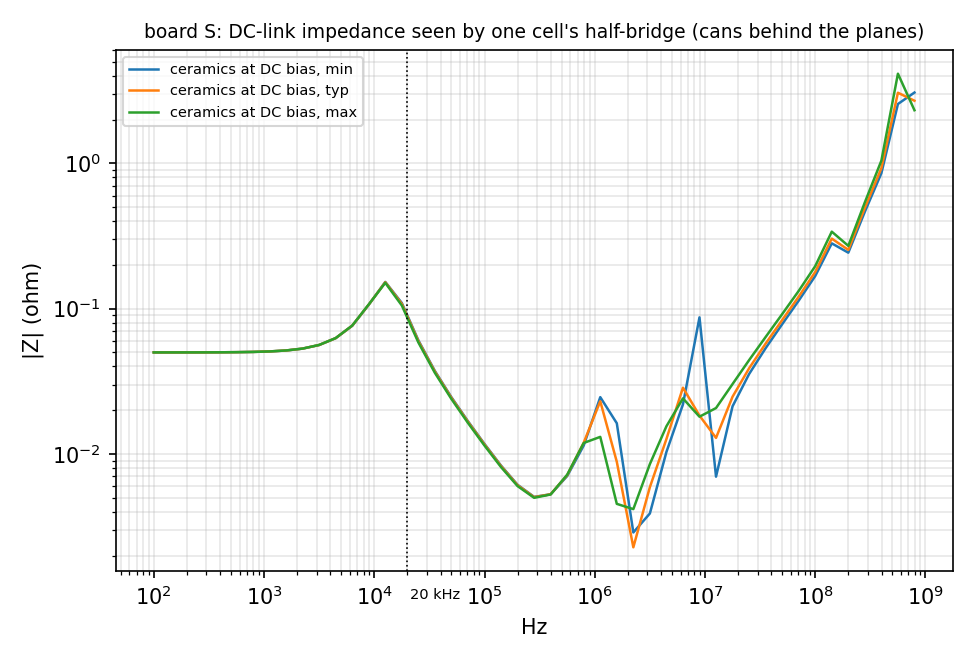
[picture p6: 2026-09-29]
sim/report/img/s/p4_dclink_z.png

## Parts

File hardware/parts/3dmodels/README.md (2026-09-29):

# 3D models

Three STEP models that footprints on the boards name but that KiCad 9's library
does not ship, and one it ships in a form its own GLB exporter cannot draw.
Nothing in the board files points here: pcbview substitutes them into a
temporary copy of the board when it exports the GLB for the pages' 3D viewer
(`[models]` in `../../../pcbview.toml` has the offsets and rotations, each
checked against the footprint in the exported model).

| File | Part | From |
|---|---|---|
| `HRO_TYPE-C-31-M-12.step` | J12, USB-C receptacle (board S) | [Keebio-Parts.pretty](https://github.com/keebio/Keebio-Parts.pretty) `3dmodels/HRO  TYPE-C-31-M-12.step`, MIT licence, Copyright (c) 2018 Keebio |
| `AOTA-B201610SR47MT.STEP` | L701, the RP2350's 2016 core-regulator inductor (boards A and S) | the model `servodrive.pretty/L_pol_2016` names, as `~/pcb/simple_earring_shipped` has it (Open CASCADE export) |
| `XT30PW-M.STEP` | J4, the XT30 bus input (board S) | `~/pcb/rp2040-motor-controller/parts/XT30PW-M--3DModel-STEP-269445.STEP`, the model the rp2040 and rp2350 motor controllers use for the same footprint (a SolidWorks 2021 export of the AMASS part; its licence is not recorded there) |
| `L_Sunlord_SWPA4030S.step` | L1001 and L1002, the bucks' 68 µH and 33 µH (board S) | KiCad 9's own `Inductor_SMD.3dshapes/L_Sunlord_SWPA4030S.step` (CC-BY-SA 4.0, KiCad libraries), flattened by `tools/flatten_step.py` (now pcbview's `pcbview/flatten.py`): the library file is a CadQuery assembly nested three deep, which `kicad-cli` 9.0.8 exports as empty nodes without a warning. Same three solids, same colours, same origin |

The SIT3088's DFN-8 (U14, U15, U17, U18) needs no file here: KiCad's own
`DFN-8-1EP_3x3mm_P0.65mm_EP1.55x2.4mm.step` stands in for its EasyEDA model.

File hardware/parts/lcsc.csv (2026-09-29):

# LCSC part numbers the project has chosen | keyed by value and footprint as
# the board files write them. tools/export_3d.py joins this into
# img/3d/<board>.parts.json for the 3D viewer's part pane; a footprint's own
# "LCSC" field | if the schematic ever carries one | wins over this table.
#
# Every part the assembler places has a row (export_3d.py warns about one
# that does not). The first twelve are the README's sourcing notes; the rest
# were chosen 2026-09-24 -- from the sister board's BOM where it had the part
# JLC basic parts where the rating allowed | and each checked against JLCPCB's
# library (model | package | rating | stock) that day. The C-number is the same
# at LCSC and JLCPCB. Notes say why where it was not obvious.
value | footprint | lcsc | mpn | note
EG2103 | SOIC-8_3.9x4.9mm_P1.27mm | C480654 | EG2103 | README Sourcing 2026-09-07
BSC030N08NS5 | TDSON-8-1_ThermalVias | C501507 | BSC030N08NS5 | README Sourcing 2026-09-07
BSC030N08NS5 | TDSON-8-1_ThermalVias_HS | C501507 | BSC030N08NS5 | README Sourcing 2026-09-07
LMR38010SDDAR | TI_SO-PowerPAD-8 | C5219310 | LMR38010SDDAR | README board S stock 2026-09-23
68u | L_Sunlord_SWPA4030S | C83473 | SWPA4030S680MT | README board S stock 2026-09-23; JLCPCB lists it, LCSC's own shop has no page for it
33u | L_Sunlord_SWPA4030S | C83470 | SWPA4030S330MT | README board S stock 2026-09-23; JLCPCB lists it, LCSC's own shop has no page for it
4u7/100V | C_1206_3216Metric | C237304 | GRM31CC72A475KE11L | README board S stock 2026-09-23
100n/100V | C_0805_2012Metric | C28233 | CL21B104KCFNNNE | README board S stock 2026-09-23
22u/25V | C_1206_3216Metric | C12891 | CL31A226KAHNNNE | README board S stock 2026-09-23
22u/25V | C_1210_3225Metric | C21397 | GRM32ER71E226KE15L | README board S stock 2026-09-23
22u/25V | C_0805_2012Metric | C45783 | CL21A226MAQNNNE | README board S stock 2026-09-23
100u/100V polymer | CP_Radial_D10.0mm_P5.00mm | C2887236 | 1011001013R00 | README board S stock 2026-09-23; board S's first bulk, two D10, until 2026-09-28 (bulk.html)
22u/100V polymer | CP_Radial_D6.3mm_P2.50mm | C49233038 | PA100V22M6X9 | jieerrui PA, 2.6 A at 100 kHz and 105 C, 30 mOhm, D6.3 x 9; 8142 in stock 2026-09-28 (second source Shengyang SH226M100E0900, C44606504)
47u/100V polymer | CP_Radial_D8.0mm_P3.50mm | C44606514 | SH476M100F1150 | Shengyang SH, 3.8 A at 100 kHz and 105 C, 28 mOhm, D8 x 11.5; 975 in stock 2026-09-28 (jieerrui PA100V47M8X11, C49233039, 2.9 A)
2.2u/100V | C_1206_3216Metric | C650969 | HMK316AC7225KLHTE | X7S 100 V; the sister board's part (rp2350-motor-controller)
100n/100V | C_0603_1608Metric | C113803 | CC0603KRX7R0BB104 | X7R 100 V, on VBUS
1u/25V | C_0603_1608Metric | C15849 | CL10A105KB8NNNC | X5R 50 V; bootstrap cap, sees 12 V; JLC basic
100n | C_0603_1608Metric | C14663 | CC0603KRX7R9BB104 | X7R 50 V; +12 V decoupling and the ADC filters; JLC basic
1n | C_0603_1608Metric | C106246 | CC0603JRNPO9BN102 | C0G 50 V; sense filter
470p/100V C0G | C_0603_1608Metric | C326973 | CC0603JRNPO0BN471 | NP0 100 V; snubber
4u7/25V | C_0603_1608Metric | C329940 | C1608X5R1V475KT000E | X5R 35 V; the sister board's part (rp2350-motor-controller)
4u7 | C_0603_1608Metric | C329940 | C1608X5R1V475KT000E | X5R 35 V; the same part as the +12 V bulk
100n | C_0402_1005Metric | C1525 | CL05B104KO5NNNC | X7R 16 V; everything it decouples is 5 V or less, the bucks' BOOT-SW caps included; JLC basic
27p | C_0402_1005Metric | C1557 | 0402CG270J500NT | C0G 50 V; crystal load
1u | C_0603_1608Metric | C15849 | CL10A105KB8NNNC | X5R 50 V; JLC basic
1u | C_0402_1005Metric | C52923 | CL05A105KA5NQNC | X5R 25 V; JLC basic
4u7 | C_0402_1005Metric | C23733 | CL05A475MP5NRNC | X5R 10 V, on +1V1 and VREG_AVDD; JLC basic
4u7 | C_0402_1005Metric_small_pads | C23733 | CL05A475MP5NRNC | X5R 10 V, on +1V1 and +3V3; JLC basic
3u3 | L_pol_2016 | C42411119 | AOTA-B201610S3R3-101-T | the RP2350 reference design's core-buck inductor
100V fast | D_SOD-323 | C2128 | 1N4148WS | 100 V repetitive, 75 V DC, 4 ns; bootstrap diode; JLC basic
TPSMF4L64A | D_SOD-123F | C1975976 | TPSMF4L64A | Littelfuse; only 60 in stock 2026-09-24
TPSMF4L54A | D_SOD-123F | C1973452 | TPSMF4L54A | Littelfuse; only 42 in stock 2026-09-24
SMDJ54A | D_SMC | C438170 | SMDJ54A | 3 kW; 54 V standoff, 60-66.3 V breakdown, 87.1 V clamp, as the spec
XT30 | AMASS_XT30PW-M_1x02_P2.50mm_Horizontal | C431092 | XT30PW-M30.G.Y | the rp2350-motor-controller's J9 (its BOM row); 68,987 in stock 2026-09-24
B5819WS | D_SOD-323 | C64886 | B5819WS | 40 V 1 A Schottky
SM712 | SOT-23 | C521963 | SM712 | RS-485 ESD
2N7002 | SOT-23 | C8545 | 2N7002 | JLC basic
USBLC6-2SC6 | SOT-23-6 | C7519 | USBLC6-2SC6 | ST
2R2 | R_0402_1005Metric | C25101 | 0402WGF220KTCE | 1%; gate resistors
2R2 | R_0603_1608Metric | C22939 | 0603WAF220KT5E | 1%; snubber; JLC basic
2m0 | R_2010_5025Metric | C413487 | WSLP20102L000FEA | Vishay 2 W metal strip, 1%; replaces the 1.6 mOhm, which no 2010 part at LCSC offers (2026-09-24)
0R | R_2010_5025Metric | C2073836 | WSL201000000ZEA9 | Vishay metal-strip jumper, 75 A, 0.2 mOhm max: it carries phase C, where a thick-film 0R carries a few amps
10R | R_0603_1608Metric | C22859 | 0603WAF100JT5E | 1%; JLC basic
10k | R_0603_1608Metric | C25804 | 0603WAF1002T5E | 1%; JLC basic
120R | R_0603_1608Metric | C22787 | 0603WAF1200T5E | 1%; RS-485 termination; JLC basic
56k 0.1% | R_0603_1608Metric | C705785 | RT0603BRD0756KL | thin film 25 ppm/K, 75 V; bus divider
4k7 0.1% | R_0603_1608Metric | C513565 | RT0603BRD074K7L | thin film 25 ppm/K; bus divider
10k 0.1% | R_0603_1608Metric | C95204 | RT0603BRD0710KL | thin film 25 ppm/K; thermistor divider
10k NTC | R_0603_1608Metric | C13564 | NCP18XH103F03RB | Murata, B25/50 = 3380 K, which the firmware's thermistor beta must match; the sister board's part (rp2350-motor-controller)
1k | R_0402_1005Metric | C11702 | 0402WGF1001TCE | 1%; JLC basic
10R | R_0402_1005Metric | C25077 | 0402WGF100JTCE | 1%; JLC basic
10k | R_0402_1005Metric | C25744 | 0402WGF1002TCE | 1%; JLC basic
33R | R_0402_1005Metric | C25105 | 0402WGF330JTCE | 1%; JLC basic
27R | R_0402_1005Metric | C25100 | 0402WGF270JTCE | 1%; the sister board's part (rp2350-motor-controller)
4k7 | R_0402_1005Metric | C25900 | 0402WGF4701TCE | 1%; JLC basic
5k1 | R_0402_1005Metric | C25905 | 0402WGF5101TCE | 1%; USB-C CC; JLC basic
15k | R_0402_1005Metric | C25756 | 0402WGF1502TCE | 1%; JLC basic
100k | R_0402_1005Metric | C25741 | 0402WGF1003TCE | 1%; JLC basic
9k09 | R_0402_1005Metric | C11549 | 0402WGF9091TCE | 1%; buck feedback
24k9 | R_0402_1005Metric | C25874 | 0402WGF2492TCE | 1%; buck feedback
64k9 | R_0402_1005Metric | C26984 | 0402WGF6492TCE | 1%; buck RT
68k | R_0402_1005Metric | C36871 | 0402WGF6802TCE | 1%; buck EN divider
470k | R_0402_1005Metric | C25790 | 0402WGF4703TCE | 1%; buck EN divider
RP2350A | RP2350-QFN-60-1EP_7x7_P0.4mm_EP3.4x3.4mm_ThermalVias | C42411118 | RP2350A | the part simple_earring uses
W25Q16JVUXIQ | Winbond_USON-8-1EP_3x2mm_P0.5mm_EP0.2x1.6mm | C2843335 | W25Q16JVUXIQ | 16 Mbit, the RP2350 reference design's flash; was W25Q128, which no USON 2x3 part offers (2026-09-24)
SPX3819-3.3 | SOT-23-5 | C20617301 | SPX3819M5-L-3-3 | the sister board's part (rp2350-motor-controller)
SPX3819M5-3.3 | SOT-23-5 | C20617301 | SPX3819M5-L-3-3 | the sister board's part (rp2350-motor-controller)
MT6701 | SOIC-8_3.9x4.9mm_P1.27mm | C3003196 | MT6701CT-STD-R | the sister board's MT6701CT-STD on reel; its C2856764 had 1 in stock
INA241A3 | TSOT-23-8 | C6051860 | INA241A3IDDFR | 50 V/V
SIT3088ETK | DFN-8_L3.0-W3.0-P0.65-BL-EP | C601076 | SIT3088ETK | the sister board's part (rp2350-motor-controller)
12MHz | Crystal_SMD_2520-4Pin_2.5x2.0mm | C284156 | TXM12M0004252LBCEO00T | CL 20 pF, 10 ppm: the 27 pF caps load it at about 16.5-18.5 pF
RGB | LED_RGB_1210 | C2827321 | S4-3528RGBTA-A | common anode, 3.5 x 2.8, pads match; PLACE ROTATED 180 deg: its pads 1-4 are B-K, A, G-K, R-K
USB-C | USB_C_Receptacle_HRO_TYPE-C-31-M-12 | C165948 | TYPE-C-31-M-12 | HRO
BOOTSEL | SW_SPST_B3U-1000P | C231329 | B3U-1000P | Omron
RS485 IN | JST_SH_SM06B-SRSS-TB_1x06-1MP_P1.00mm_Horizontal | C3029345 | WAFER-SH1.0-6PWB | SH-compatible; JST's own C160405 had 3 in stock; check its land pattern against the footprint
RS485 OUT | JST_SH_SM06B-SRSS-TB_1x06-1MP_P1.00mm_Horizontal | C3029345 | WAFER-SH1.0-6PWB | SH-compatible; JST's own C160405 had 3 in stock; check its land pattern against the footprint
EXPANSION | PinHeader_2x10_P1.27mm_Vertical_SMD | C59981 | 1.27-2*10PVertical SMD Pin | 3 A per pin
SIG_LINK | PinHeader_2x14_P1.27mm_Vertical_SMD | C41427103 | A127M05-0B28P51-H10A40 | the only 2x14 1.27 mm SMD male header at JLCPCB; 50 in stock 2026-09-24
PWR_LINK | PinHeader_2x05_P2.54mm_Vertical | C32713278 | HX PZ2.54-2x5P ZZ | 3 A per pin, gold

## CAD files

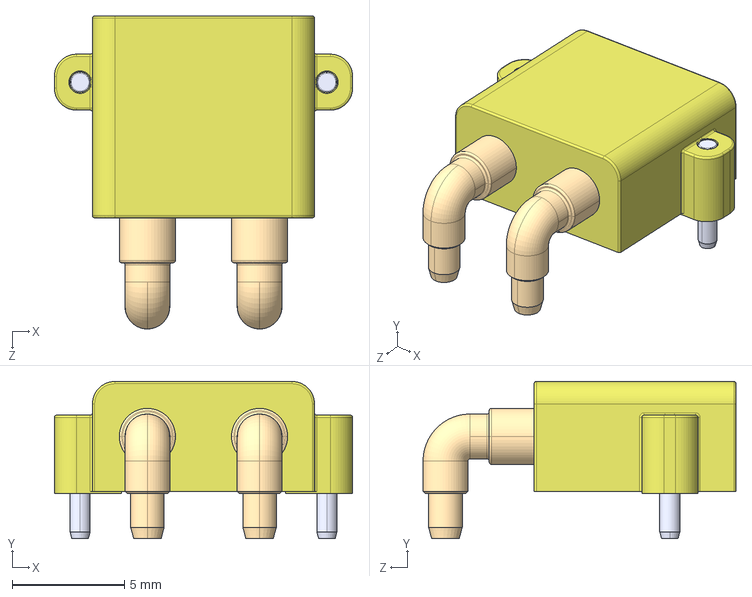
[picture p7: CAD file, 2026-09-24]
hardware/parts/3dmodels/XT30PW-M.STEP
13.3 x 7.00 x 14.0 mm

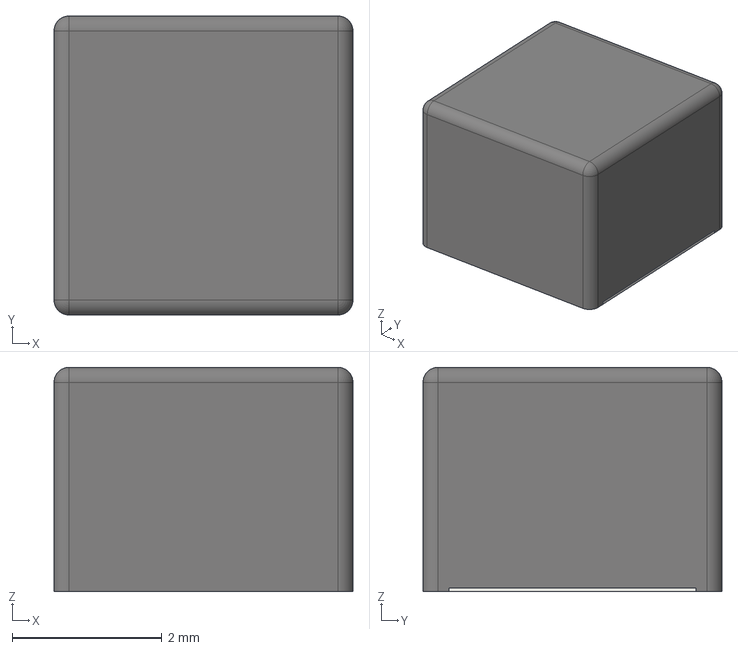
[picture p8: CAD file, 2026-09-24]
hardware/parts/3dmodels/L_Sunlord_SWPA4030S.step
4.00 x 4.00 x 3.00 mm

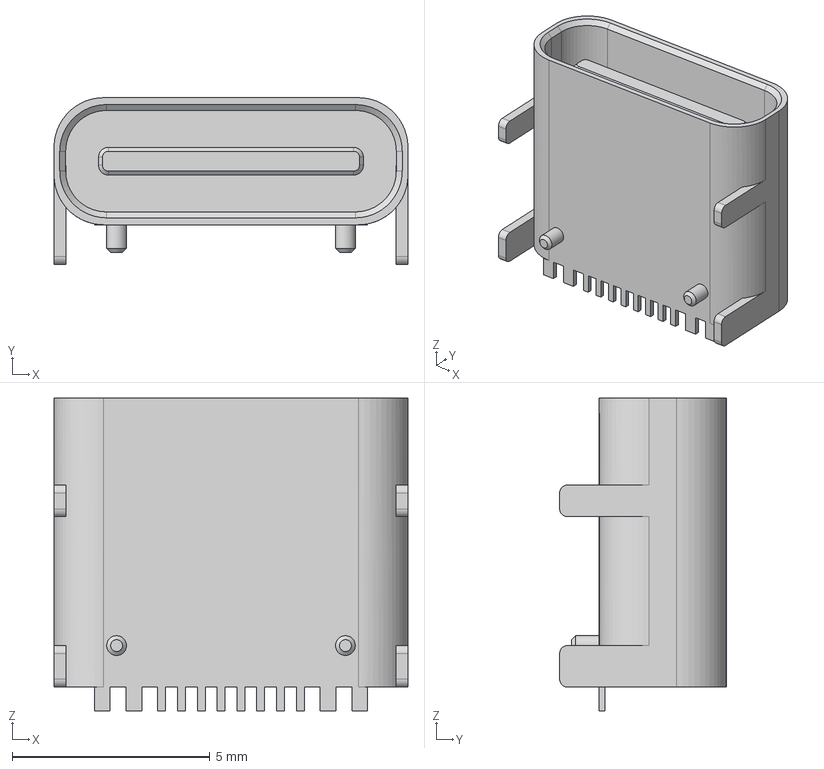
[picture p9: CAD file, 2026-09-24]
hardware/parts/3dmodels/HRO_TYPE-C-31-M-12.step
8.94 x 4.21 x 7.90 mm

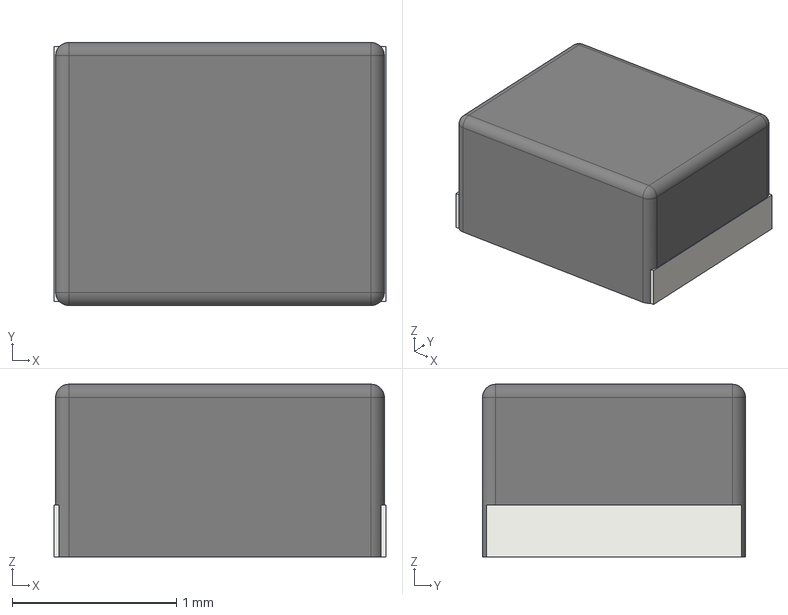
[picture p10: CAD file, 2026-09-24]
hardware/parts/3dmodels/AOTA-B201610SR47MT.STEP
2.02 x 1.60 x 1.05 mm

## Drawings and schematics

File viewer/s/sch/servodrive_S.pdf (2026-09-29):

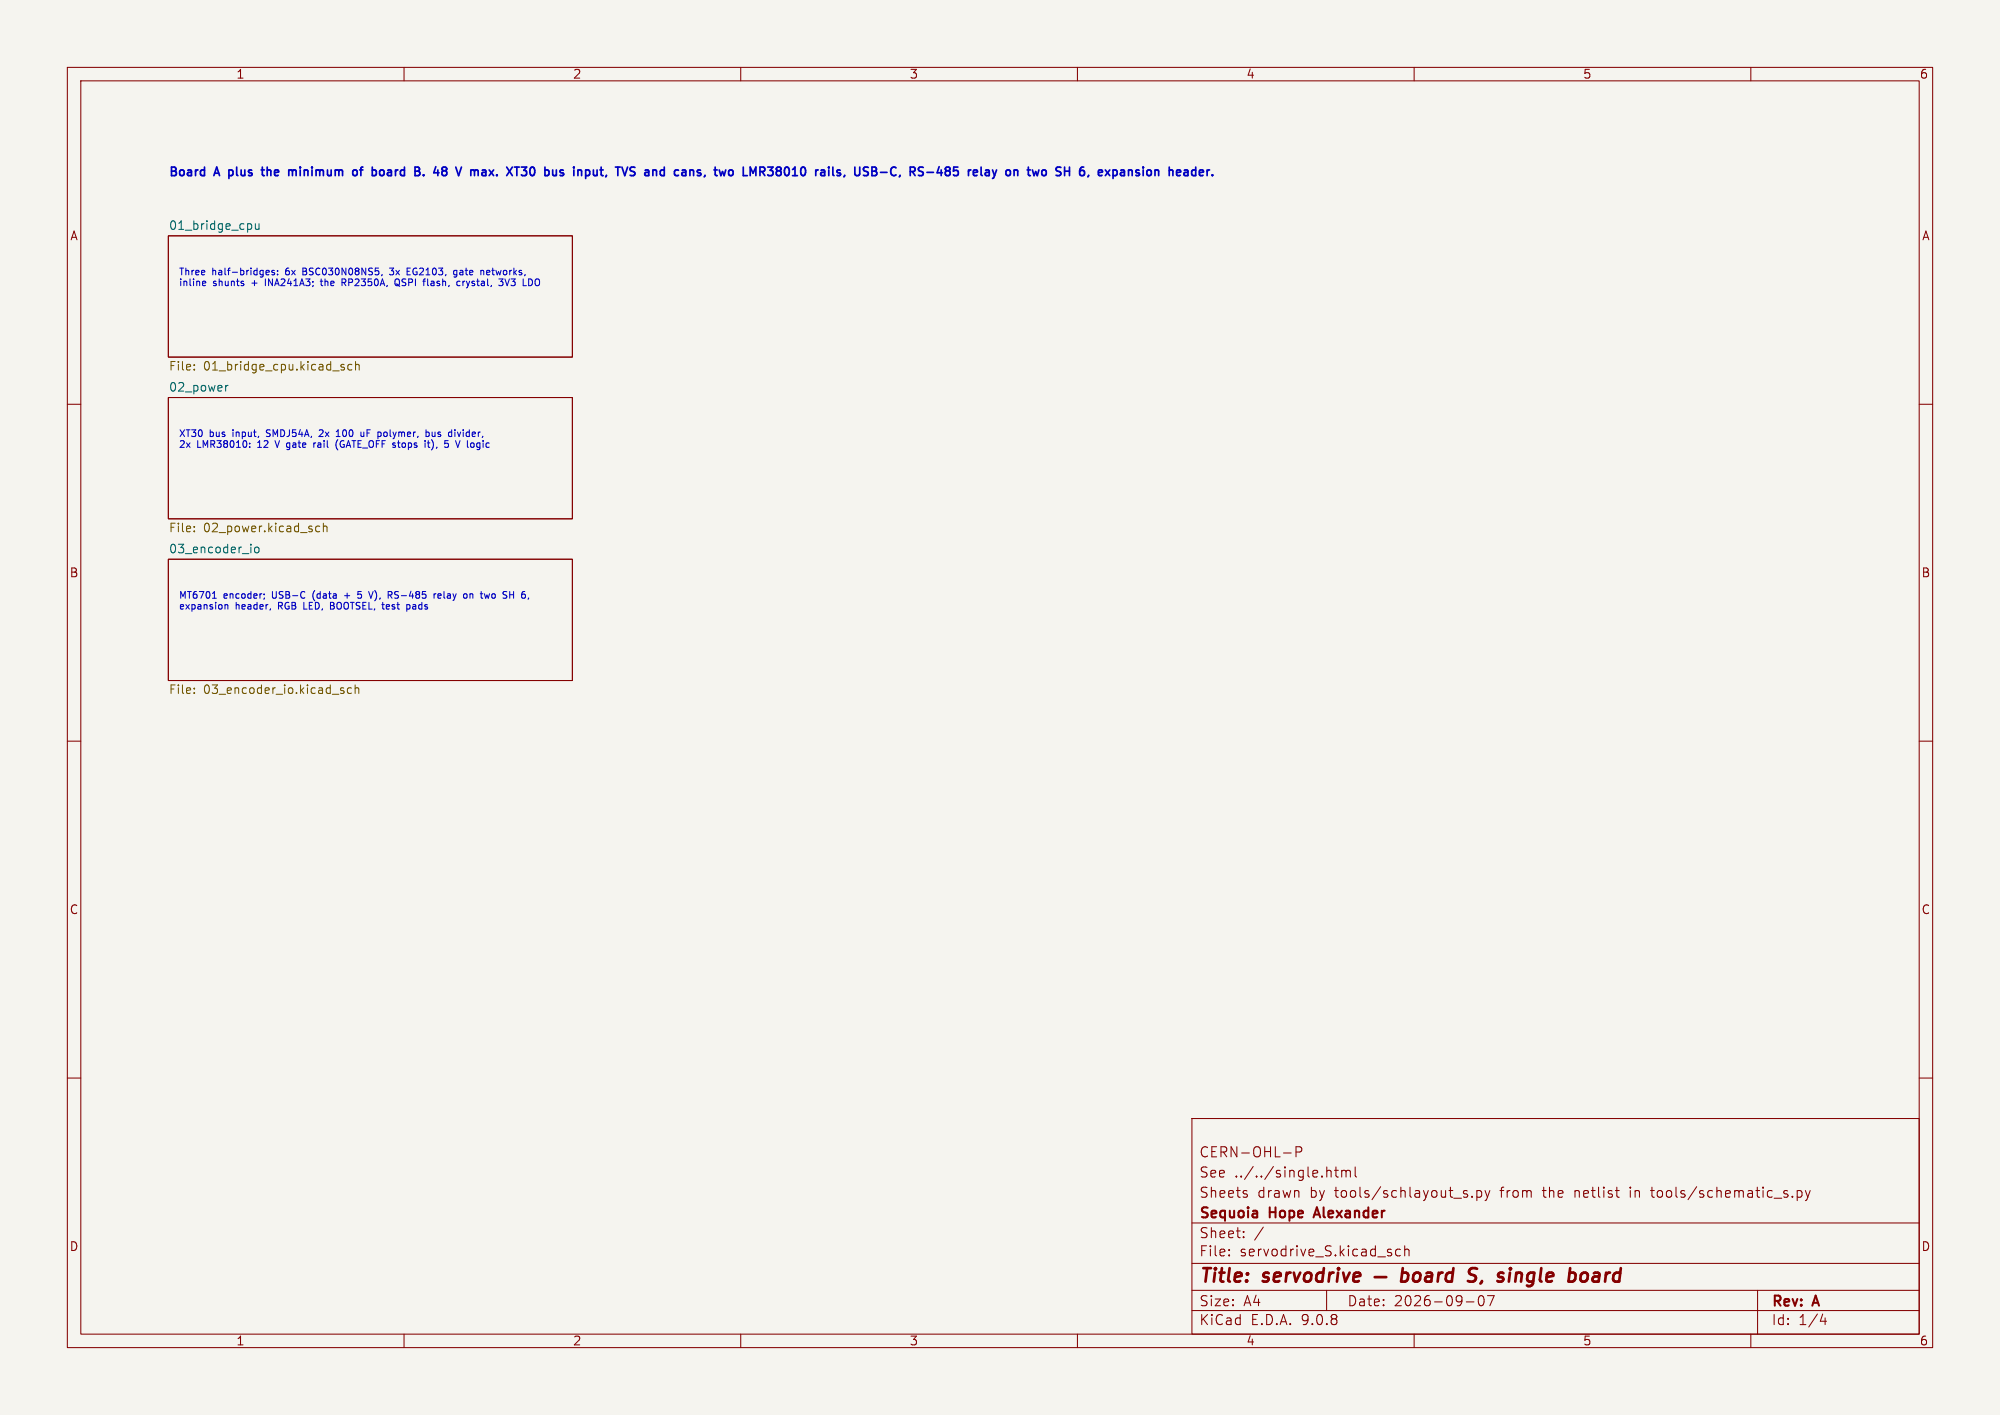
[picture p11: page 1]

Id: 1/4 Title: servodrive þÿ board S, single board

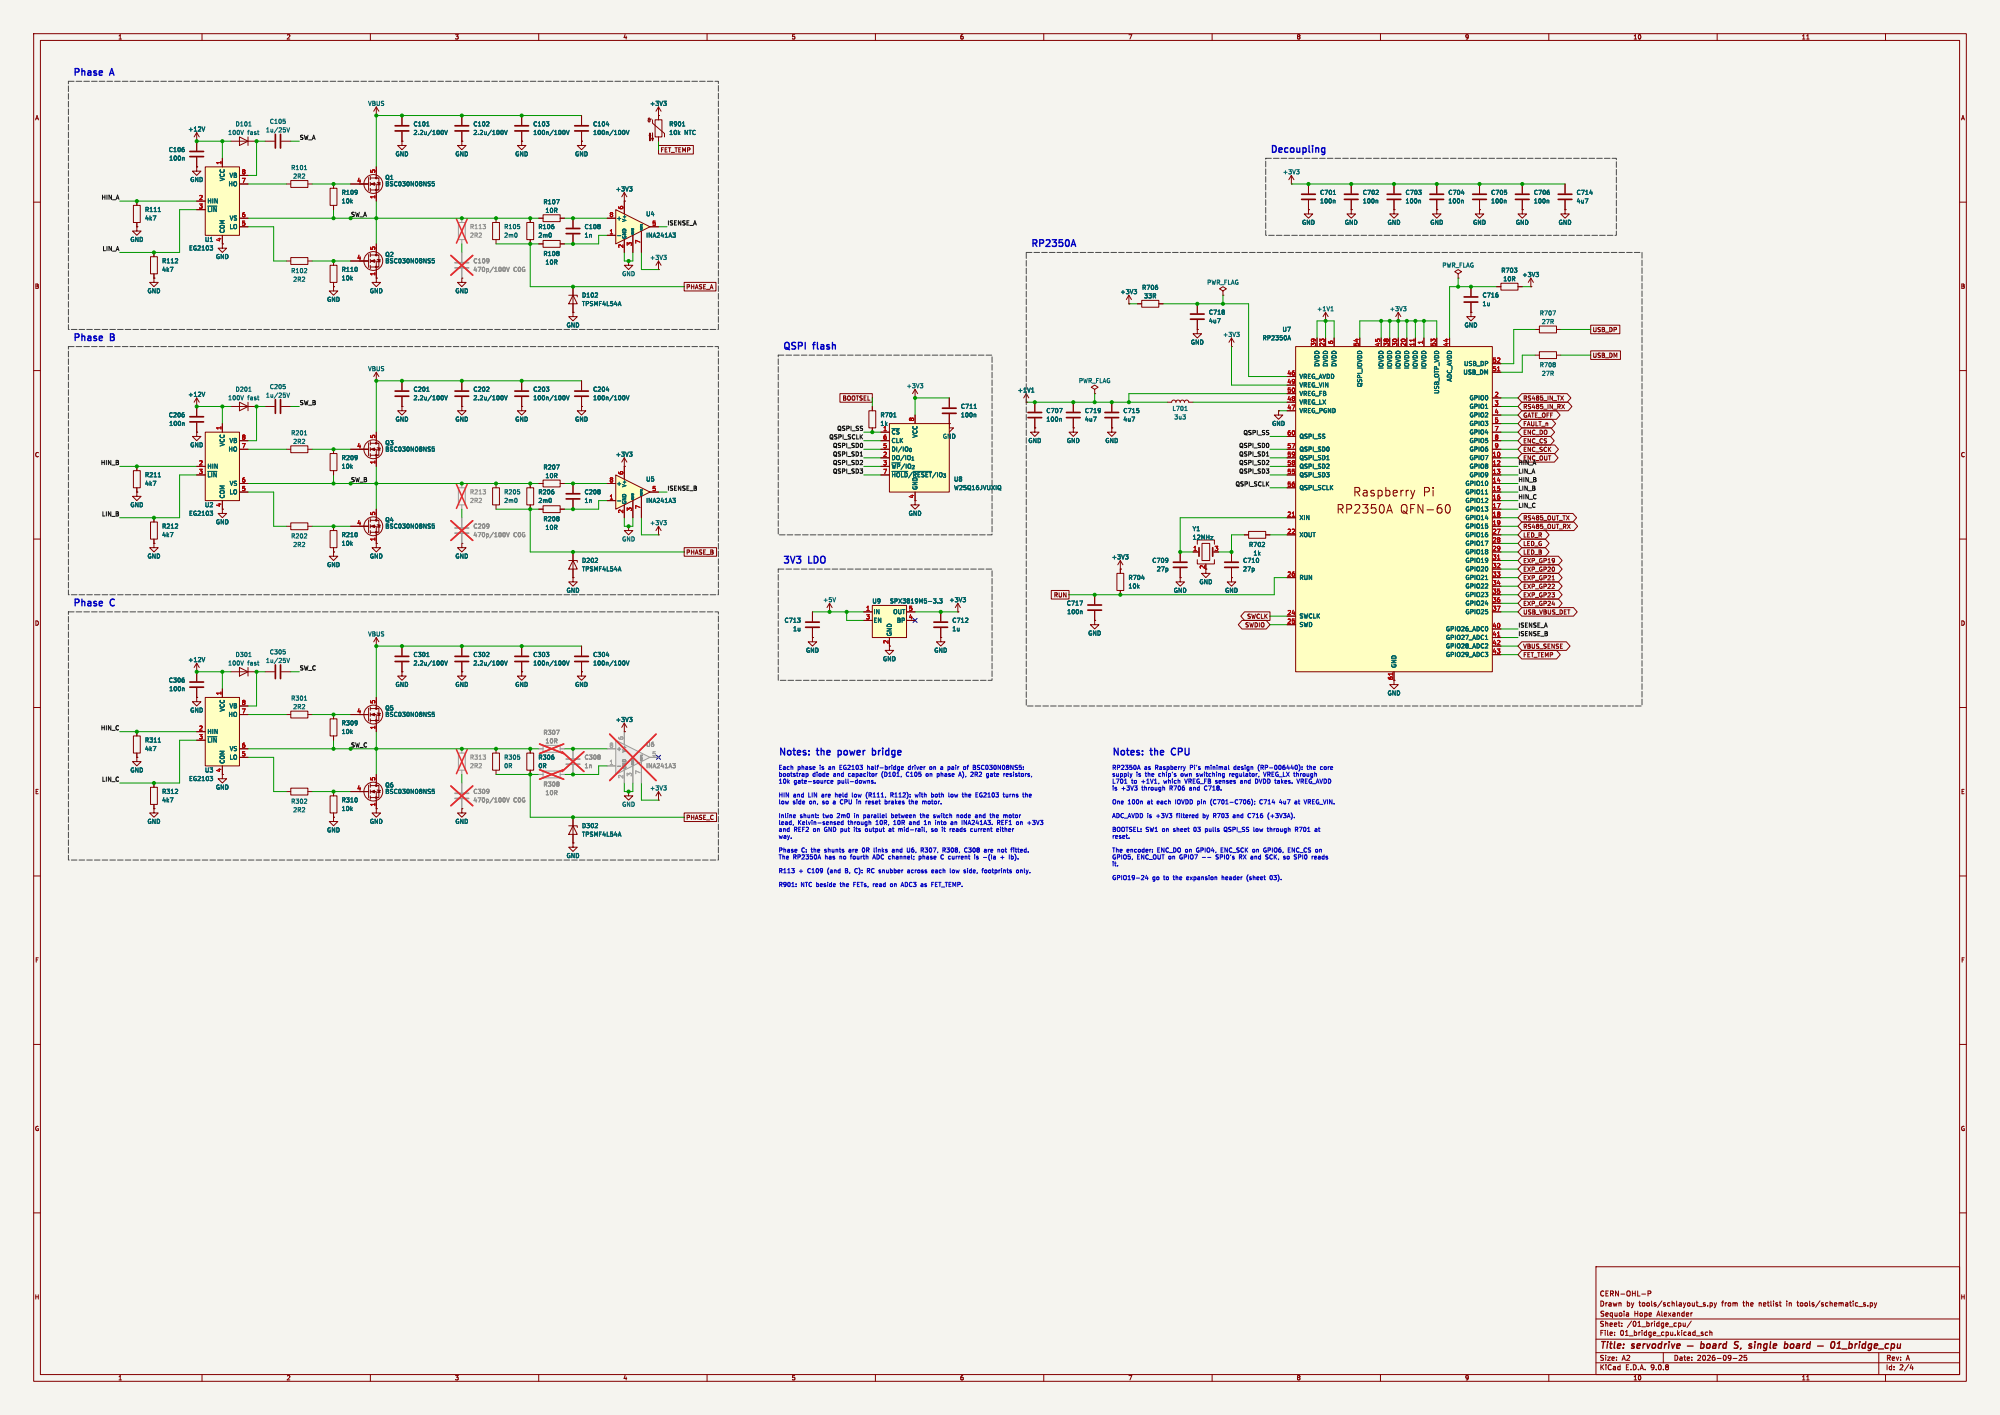
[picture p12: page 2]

6 QSPI_IOVDD 54 IOVDD 45 IOVDD 38 GND 61 IOVDD 30 IOVDD 20 IOVDD 11 IOVDD

Notes: the power bridge

L701 to +1V1, which VREG_FB senses and DVDD takes. VREG_AVDD

low side on, so a CPU in reset brakes the motor.

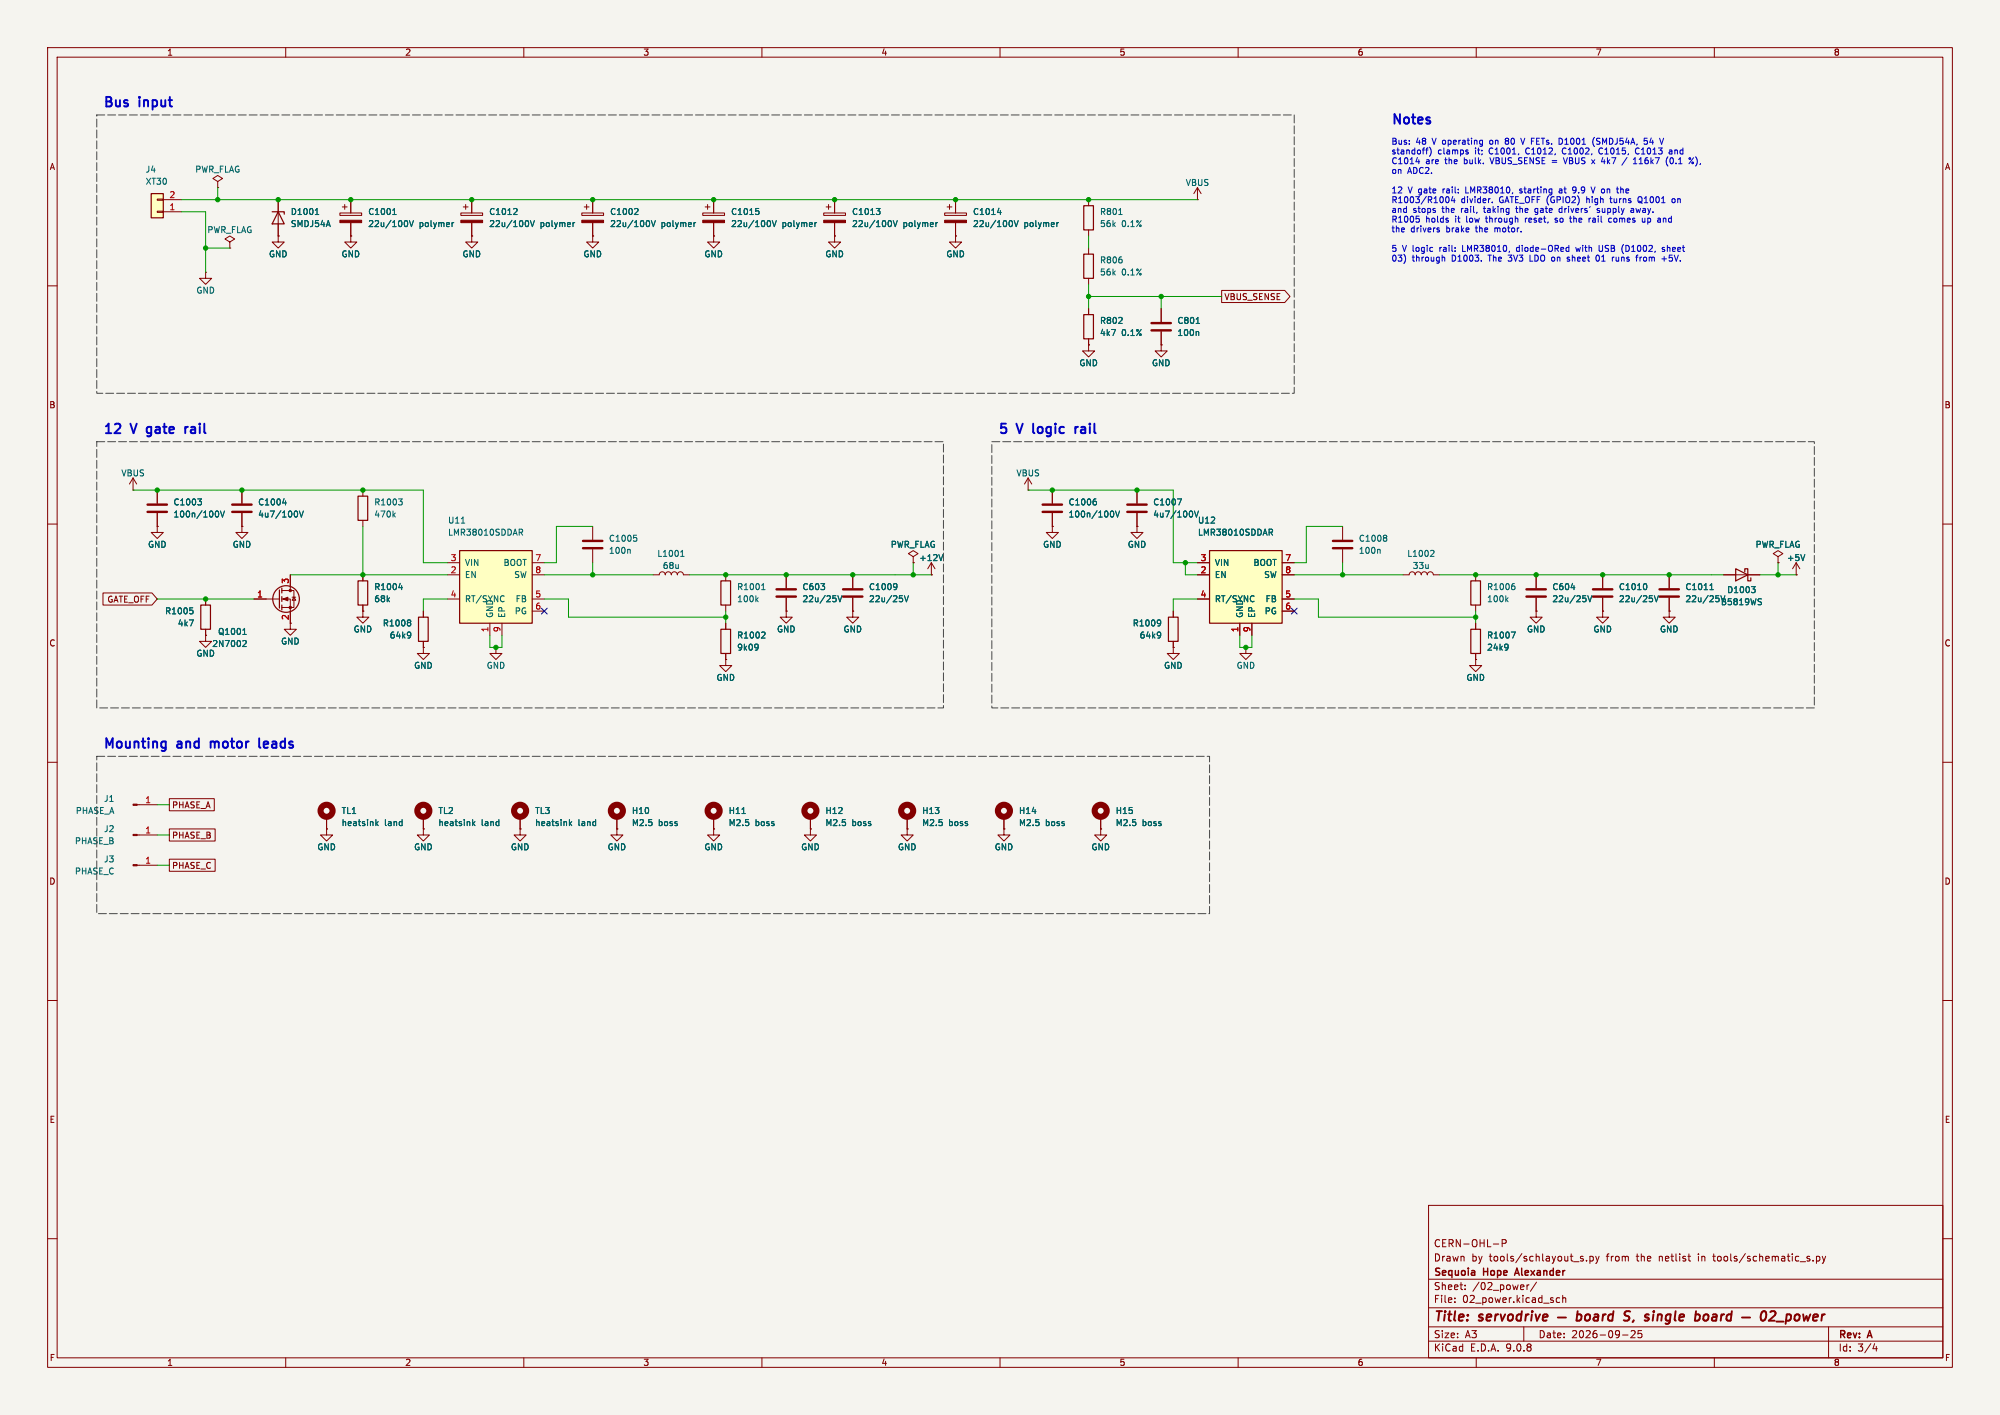
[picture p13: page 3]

9 BOOT 7 SW 8 FB 5 PG 6 U11
LMR38010SDDAR

9 BOOT 7 SW 8 FB 5 PG 6 U12

9 BOOT 7 SW 8 FB 5 PG 6 GND GND
+5V GND GND

Mounting and motor leads

Id: 3/4 Title: servodrive þÿ board S, single board þÿ 02_power File: 02_power.kicad_sch Sheet: /02_power/

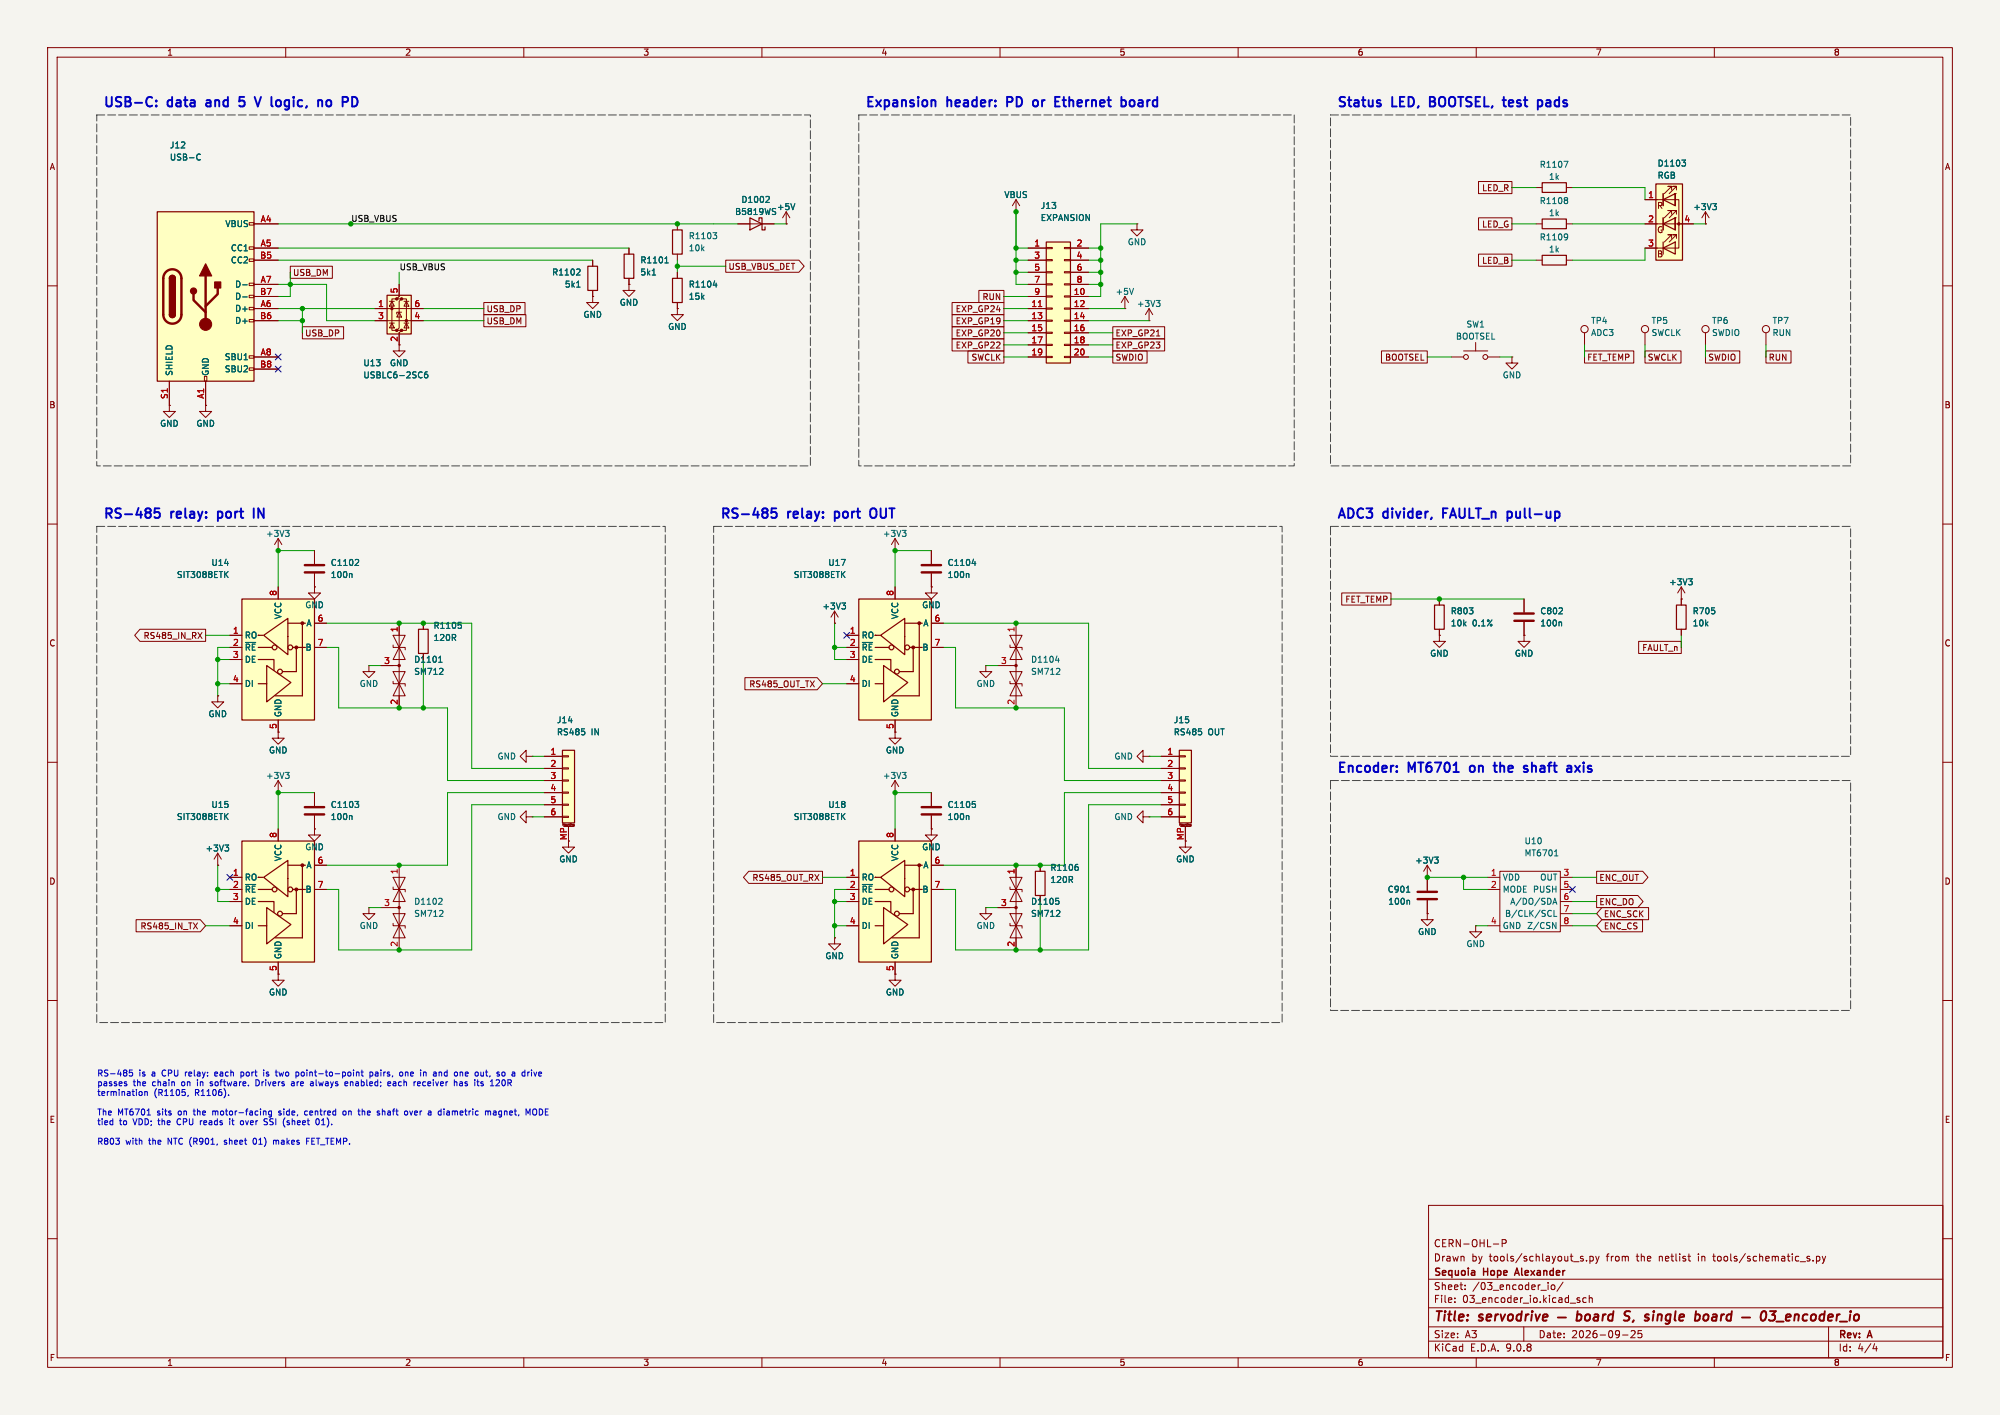
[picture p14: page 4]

Status LED, BOOTSEL, test pads

File: 03_encoder_io.kicad_sch Sheet: /03_encoder_io/
Id: 4/4 Title: servodrive þÿ board S, single board þÿ 03_encoder_io

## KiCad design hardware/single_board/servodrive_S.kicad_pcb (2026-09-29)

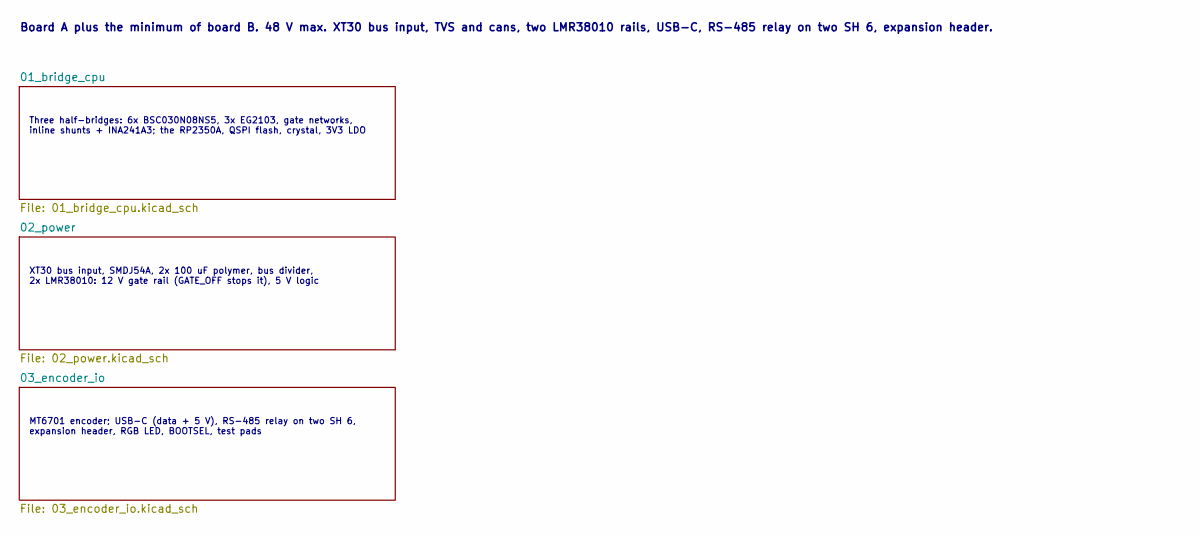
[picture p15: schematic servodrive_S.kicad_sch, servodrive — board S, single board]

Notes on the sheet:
Three half-bridges: 6x BSC030N08NS5, 3x EG2103, gate networks, inline shunts + INA241A3; the RP2350A, QSPI flash, crystal, 3V3 LDO
XT30 bus input, SMDJ54A, 2x 100 uF polymer, bus divider, 2x LMR38010: 12 V gate rail (GATE_OFF stops it), 5 V logic
MT6701 encoder; USB-C (data + 5 V), RS-485 relay on two SH 6, expansion header, RGB LED, BOOTSEL, test pads
Board A plus the minimum of board B. 48 V max. XT30 bus input, TVS and cans, two LMR38010 rails, USB-C, RS-485 relay on two SH 6, expansion header.

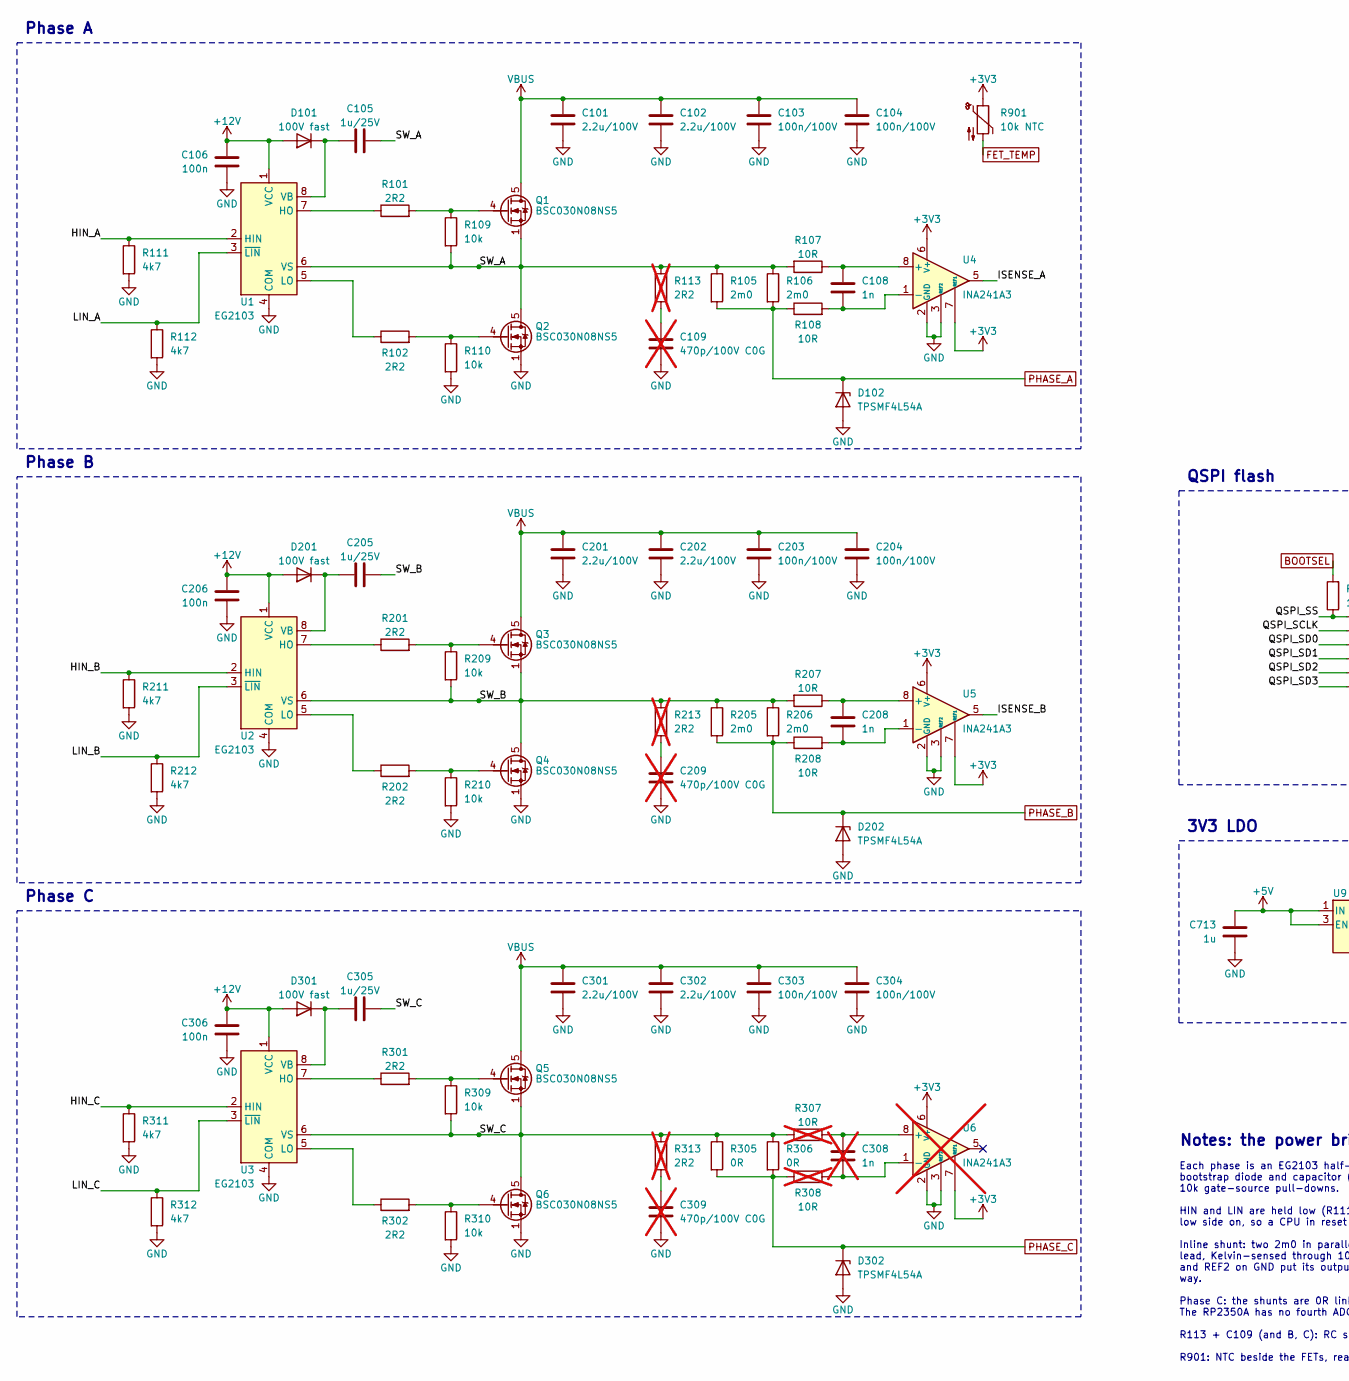
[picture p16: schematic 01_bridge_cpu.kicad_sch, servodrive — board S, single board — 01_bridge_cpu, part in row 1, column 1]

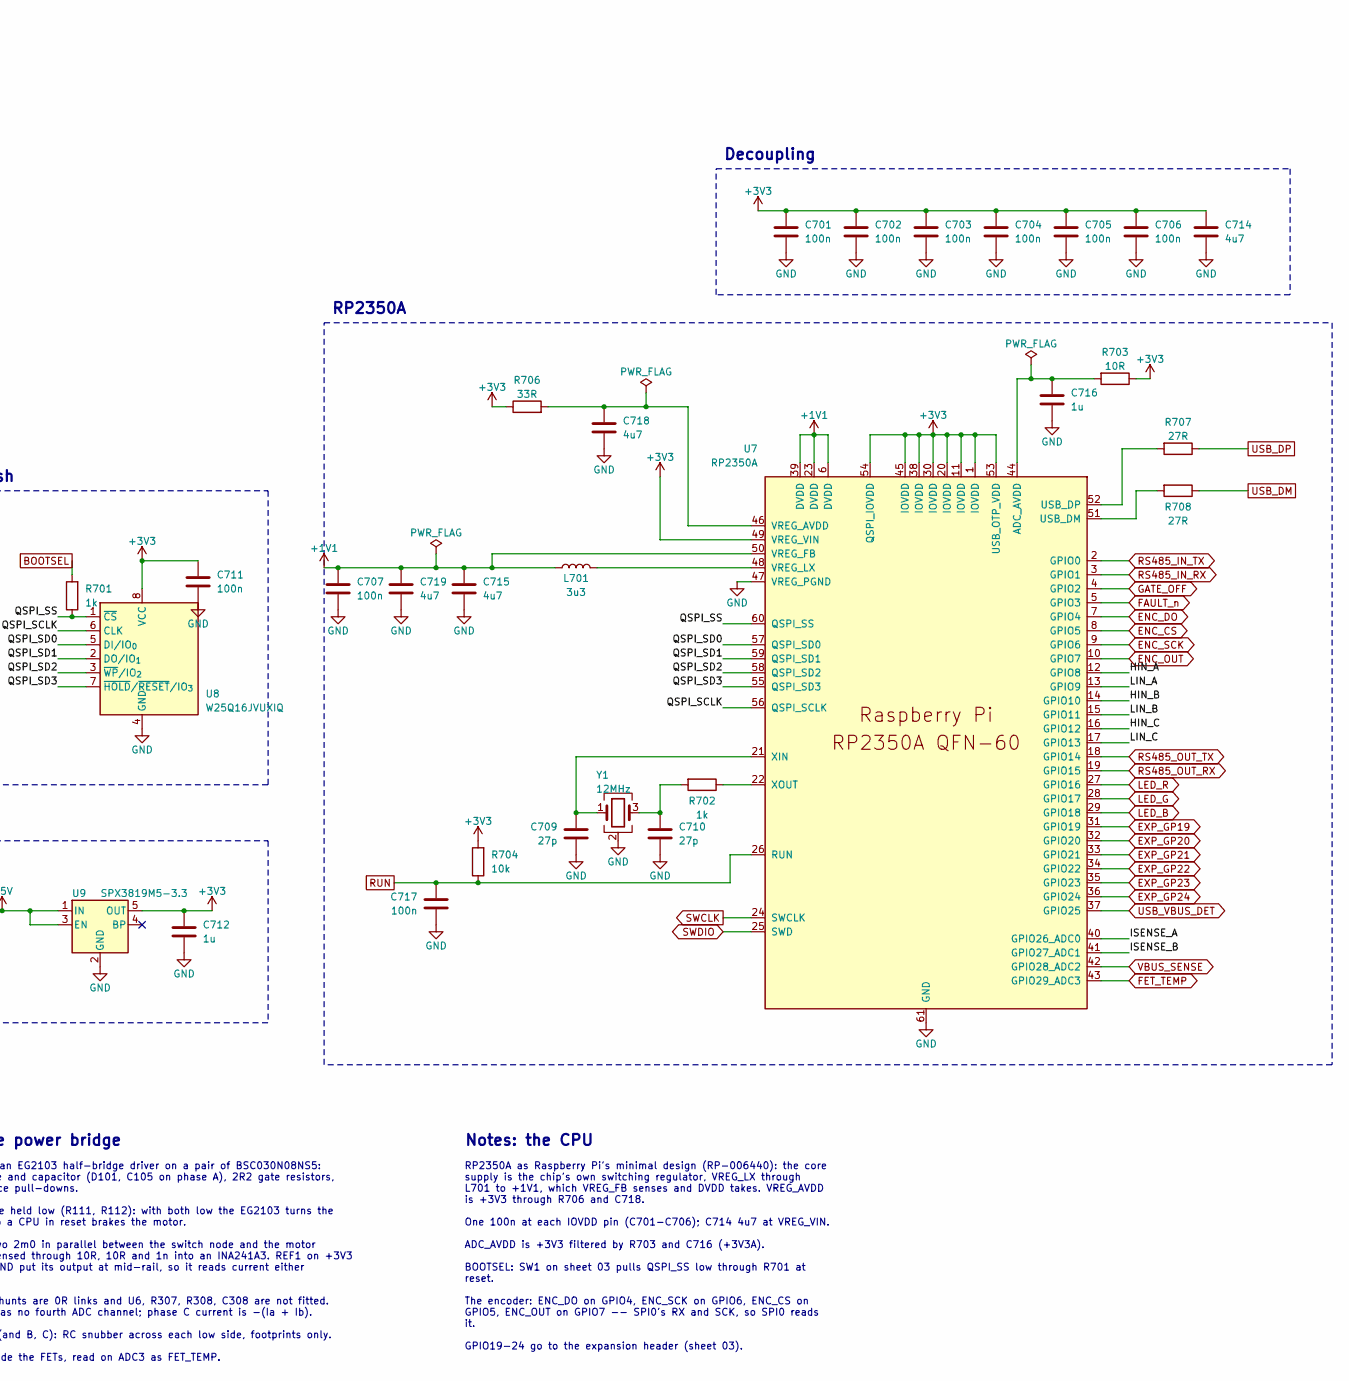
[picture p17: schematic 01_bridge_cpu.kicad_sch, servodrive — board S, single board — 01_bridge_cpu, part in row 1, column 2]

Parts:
C101, C102, C201, C202, C301, C302: 2.2u/100V; C_1206_3216Metric
C103, C104, C203, C204, C303, C304: 100n/100V; C_0603_1608Metric
C105, C205, C305: 1u/25V; C_0603_1608Metric
C106, C206, C306: 100n; C_0603_1608Metric
C108, C208: 1n; C_0603_1608Metric
C109, C209, C309: 470p/100V C0G; C_0603_1608Metric; not fitted
C308: 1n; C_0603_1608Metric; not fitted
C701, C702, C703, C704, C705, C706, C707, C711, C717: 100n; C_0402_1005Metric
C709, C710: 27p; C_0402_1005Metric
C712, C713: 1u; C_0603_1608Metric
C714, C715: 4u7; C_0402_1005Metric_small_pads
C716: 1u; C_0402_1005Metric
C718, C719: 4u7; C_0402_1005Metric
D101, D201, D301: 100V fast; D_SOD-323
D102, D202, D302: TPSMF4L54A; D_SOD-123F
L701: 3u3; L_pol_2016
Q1, Q3, Q5: BSC030N08NS5; TDSON-8-1_ThermalVias_HS
Q2, Q4, Q6: BSC030N08NS5; TDSON-8-1_ThermalVias
R101, R102, R201, R202, R301, R302: 2R2; R_0402_1005Metric
R105, R106, R205, R206: 2m0; R_2010_5025Metric
R107, R108, R207, R208: 10R; R_0603_1608Metric
R109, R110, R209, R210, R309, R310: 10k; R_0603_1608Metric
R111, R112, R211, R212, R311, R312: 4k7; R_0402_1005Metric
R113, R213, R313: 2R2; R_0603_1608Metric; not fitted
R305, R306: 0R; R_2010_5025Metric
R307, R308: 10R; R_0603_1608Metric; not fitted
R701, R702: 1k; R_0402_1005Metric
R703: 10R; R_0402_1005Metric
R704: 10k; R_0402_1005Metric
R706: 33R; R_0402_1005Metric
R707, R708: 27R; R_0402_1005Metric
R901: 10k NTC; R_0603_1608Metric
U1, U2, U3: EG2103; SOIC-8_3.9x4.9mm_P1.27mm
U4, U5: INA241A3; TSOT-23-8
U6: INA241A3; TSOT-23-8; not fitted
U7: RP2350A; RP2350-QFN-60-1EP_7x7_P0.4mm_EP3.4x3.4mm_ThermalVias
U8: W25Q16JVUXIQ; Winbond_USON-8-1EP_3x2mm_P0.5mm_EP0.2x1.6mm
U9: SPX3819M5-3.3; SOT-23-5
Y1: 12MHz; Crystal_SMD_2520-4Pin_2.5x2.0mm

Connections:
+1V1: C707.1, C715.1, C719.1, L701.1, U7.6 (DVDD), U7.23 (DVDD), U7.39 (DVDD), U7.50 (VREG_FB)
+3V3: C701.1, C702.1, C703.1, C704.1, C705.1, C706.1, C711.1, C712.1, C714.1, R703.1, R704.2, R706.1, R901.1, U4.6 (V+), U4.7 (REF1), U5.6 (V+), U5.7 (REF1), U6.6 (V+), U6.7 (REF1), U7.1 (IOVDD), U7.11 (IOVDD), U7.20 (IOVDD), U7.30 (IOVDD), U7.38 (IOVDD), U7.45 (IOVDD), U7.49 (VREG_VIN), U7.53 (USB_OTP_VDD), U7.54 (QSPI_IOVDD), U8.8 (VCC), U9.5 (OUT); also elsewhere on the board
+3V3A: C716.1, R703.2, U7.44 (ADC_AVDD)
+5V: C713.1, U9.1 (IN), U9.3 (EN); also elsewhere on the board
+12V: C106.1, C206.1, C306.1, D101.2 (A), D201.2 (A), D301.2 (A), U1.1 (VCC), U2.1 (VCC), U3.1 (VCC); also elsewhere on the board
BOOTSEL: R701.2; also elsewhere on the board
ENC_CS: U7.8 (GPIO5); also elsewhere on the board
ENC_DO: U7.7 (GPIO4); also elsewhere on the board
ENC_OUT: U7.10 (GPIO7); also elsewhere on the board
ENC_SCK: U7.9 (GPIO6); also elsewhere on the board
EXP_GP19: U7.31 (GPIO19); also elsewhere on the board
EXP_GP20: U7.32 (GPIO20); also elsewhere on the board
EXP_GP21: U7.33 (GPIO21); also elsewhere on the board
EXP_GP22: U7.34 (GPIO22); also elsewhere on the board
EXP_GP23: U7.35 (GPIO23); also elsewhere on the board
EXP_GP24: U7.36 (GPIO24); also elsewhere on the board
FAULT_n: U7.5 (GPIO3); also elsewhere on the board
FET_TEMP: R901.2, U7.43 (GPIO29_ADC3); also elsewhere on the board
GATE_OFF: U7.4 (GPIO2); also elsewhere on the board
GH_A: Q1.4 (G), R101.2, R109.1
GH_B: Q3.4 (G), R201.2, R209.1
GH_C: Q5.4 (G), R301.2, R309.1
GL_A: Q2.4 (G), R102.2, R110.1
GL_B: Q4.4 (G), R202.2, R210.1
GL_C: Q6.4 (G), R302.2, R310.1
GND: C101.2, C102.2, C103.2, C104.2, C106.2, C109.1, C201.2, C202.2, C203.2, C204.2, C206.2, C209.1, C301.2, C302.2, C303.2, C304.2, C306.2, C309.1, C701.2, C702.2, C703.2, C704.2, C705.2, C706.2, C707.2, C709.2, C710.2, C711.2, C712.2, C713.2, C714.2, C715.2, C716.2, C717.2, C718.2, C719.2, D102.2 (A), D202.2 (A), D302.2 (A), Q2.1 (S), Q2.2 (S), Q2.3 (S), Q4.1 (S), Q4.2 (S), Q4.3 (S), Q6.1 (S), Q6.2 (S), Q6.3 (S), R110.2, R111.2, R112.2, R210.2, R211.2, R212.2, R310.2, R311.2, R312.2, U1.4 (COM), U2.4 (COM), U3.4 (COM), U4.2 (GND), U4.3 (REF2), U4.4 (GND), U5.2 (GND), U5.3 (REF2), U5.4 (GND), U6.2 (GND), U6.3 (REF2), U6.4 (GND), U7.47 (VREG_PGND), U7.61 (GND), U8.4 (GND), U9.2 (GND), Y1.2 (G), Y1.4 (G); also elsewhere on the board
HIN_A: R111.1, U1.2 (HIN), U7.12 (GPIO8)
HIN_B: R211.1, U2.2 (HIN), U7.14 (GPIO10)
HIN_C: R311.1, U3.2 (HIN), U7.16 (GPIO12)
HO_A: R101.1, U1.7 (HO)
HO_B: R201.1, U2.7 (HO)
HO_C: R301.1, U3.7 (HO)
ISENSE_A: U4.5, U7.40 (GPIO26_ADC0)
ISENSE_B: U5.5, U7.41 (GPIO27_ADC1)
LED_B: U7.29 (GPIO18); also elsewhere on the board
LED_G: U7.28 (GPIO17); also elsewhere on the board
LED_R: U7.27 (GPIO16); also elsewhere on the board
LIN_A: R112.1, U1.3 (~LIN), U7.13 (GPIO9)
LIN_B: R212.1, U2.3 (~LIN), U7.15 (GPIO11)
LIN_C: R312.1, U3.3 (~LIN), U7.17 (GPIO13)
LO_A: R102.1, U1.5 (LO)
LO_B: R202.1, U2.5 (LO)
LO_C: R302.1, U3.5 (LO)
PHASE_A: D102.1 (K), R105.2, R106.2, R108.1; also elsewhere on the board
PHASE_B: D202.1 (K), R205.2, R206.2, R208.1; also elsewhere on the board
PHASE_C: D302.1 (K), R305.2, R306.2, R308.1; also elsewhere on the board
QSPI_SCLK: U7.56 (QSPI_SCLK), U8.6 (CLK)
QSPI_SD0: U7.57 (QSPI_SD0), U8.5 (DI/IO_{0})
QSPI_SD1: U7.59 (QSPI_SD1), U8.2 (DO/IO_{1})
QSPI_SD2: U7.58 (QSPI_SD2), U8.3 (~WP/IO_{2})
QSPI_SD3: U7.55 (QSPI_SD3), U8.7 (~HOLD/~RESET/IO_{3})
QSPI_SS: R701.1, U7.60 (QSPI_SS), U8.1 (~CS)
RS485_IN_RX: U7.3 (GPIO1); also elsewhere on the board
RS485_IN_TX: U7.2 (GPIO0); also elsewhere on the board
RS485_OUT_RX: U7.19 (GPIO15); also elsewhere on the board
RS485_OUT_TX: U7.18 (GPIO14); also elsewhere on the board
RUN: C717.1, R704.1, U7.26 (RUN); also elsewhere on the board
SNSN_A: C108.2, R108.2, U4.1 (-)
SNSN_B: C208.2, R208.2, U5.1 (-)
SNSN_C: C308.2, R308.2, U6.1 (-)
SNSP_A: C108.1, R107.1, U4.8 (+)
SNSP_B: C208.1, R207.1, U5.8 (+)
SNSP_C: C308.1, R307.1, U6.8 (+)
SNUB_A: C109.2, R113.1
SNUB_B: C209.2, R213.1
SNUB_C: C309.2, R313.1
SWCLK: U7.24 (SWCLK); also elsewhere on the board
SWDIO: U7.25 (SWD); also elsewhere on the board
SW_A: C105.2, Q1.1 (S), Q1.2 (S), Q1.3 (S), Q2.5 (D), R105.1, R106.1, R107.2, R109.2, R113.2, U1.6 (VS)
SW_B: C205.2, Q3.1 (S), Q3.2 (S), Q3.3 (S), Q4.5 (D), R205.1, R206.1, R207.2, R209.2, R213.2, U2.6 (VS)
SW_C: C305.2, Q5.1 (S), Q5.2 (S), Q5.3 (S), Q6.5 (D), R305.1, R306.1, R307.2, R309.2, R313.2, U3.6 (VS)
USB_DM: R708.1; also elsewhere on the board
USB_DM_C: R708.2, U7.51 (USB_DM)
USB_DP: R707.1; also elsewhere on the board
USB_DP_C: R707.2, U7.52 (USB_DP)
USB_VBUS_DET: U7.37 (GPIO25); also elsewhere on the board
VBUS: C101.1, C102.1, C103.1, C104.1, C201.1, C202.1, C203.1, C204.1, C301.1, C302.1, C303.1, C304.1, Q1.5 (D), Q3.5 (D), Q5.5 (D); also elsewhere on the board
VBUS_SENSE: U7.42 (GPIO28_ADC2); also elsewhere on the board
VB_A: C105.1, D101.1 (K), U1.8 (VB)
VB_B: C205.1, D201.1 (K), U2.8 (VB)
VB_C: C305.1, D301.1 (K), U3.8 (VB)
VREG_AVDD: C718.1, R706.2, U7.46 (VREG_AVDD)
VREG_LX: L701.2, U7.48 (VREG_LX)
XIN: C709.1, U7.21 (XIN), Y1.1
XOUT: R702.1, U7.22 (XOUT)
XTAL2: C710.1, R702.2, Y1.3

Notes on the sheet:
Phase A
Phase B
Phase C
RP2350A
QSPI flash
3V3 LDO
Decoupling
Notes: the power bridge
Each phase is an EG2103 half-bridge driver on a pair of BSC030N08NS5: bootstrap diode and capacitor (D101, C105 on phase A), 2R2 gate resistors, 10k gate-source pull-downs. HIN and LIN are held low (R111, R112): with both low the EG2103 turns the low side on, so a CPU in reset brakes the motor. Inl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
Notes: the CPU
RP2350A as Raspberry Pi's minimal design (RP-006440): the core supply is the chip's own switching regulator, VREG_LX through L701 to +1V1, which VREG_FB senses and DVDD takes. VREG_AVDD is +3V3 through R706 and C718. One 100n at each IOVDD pin (C701-C706); C714 4u7 at VREG_VIN. ADC_AVDD is +3V3 fil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

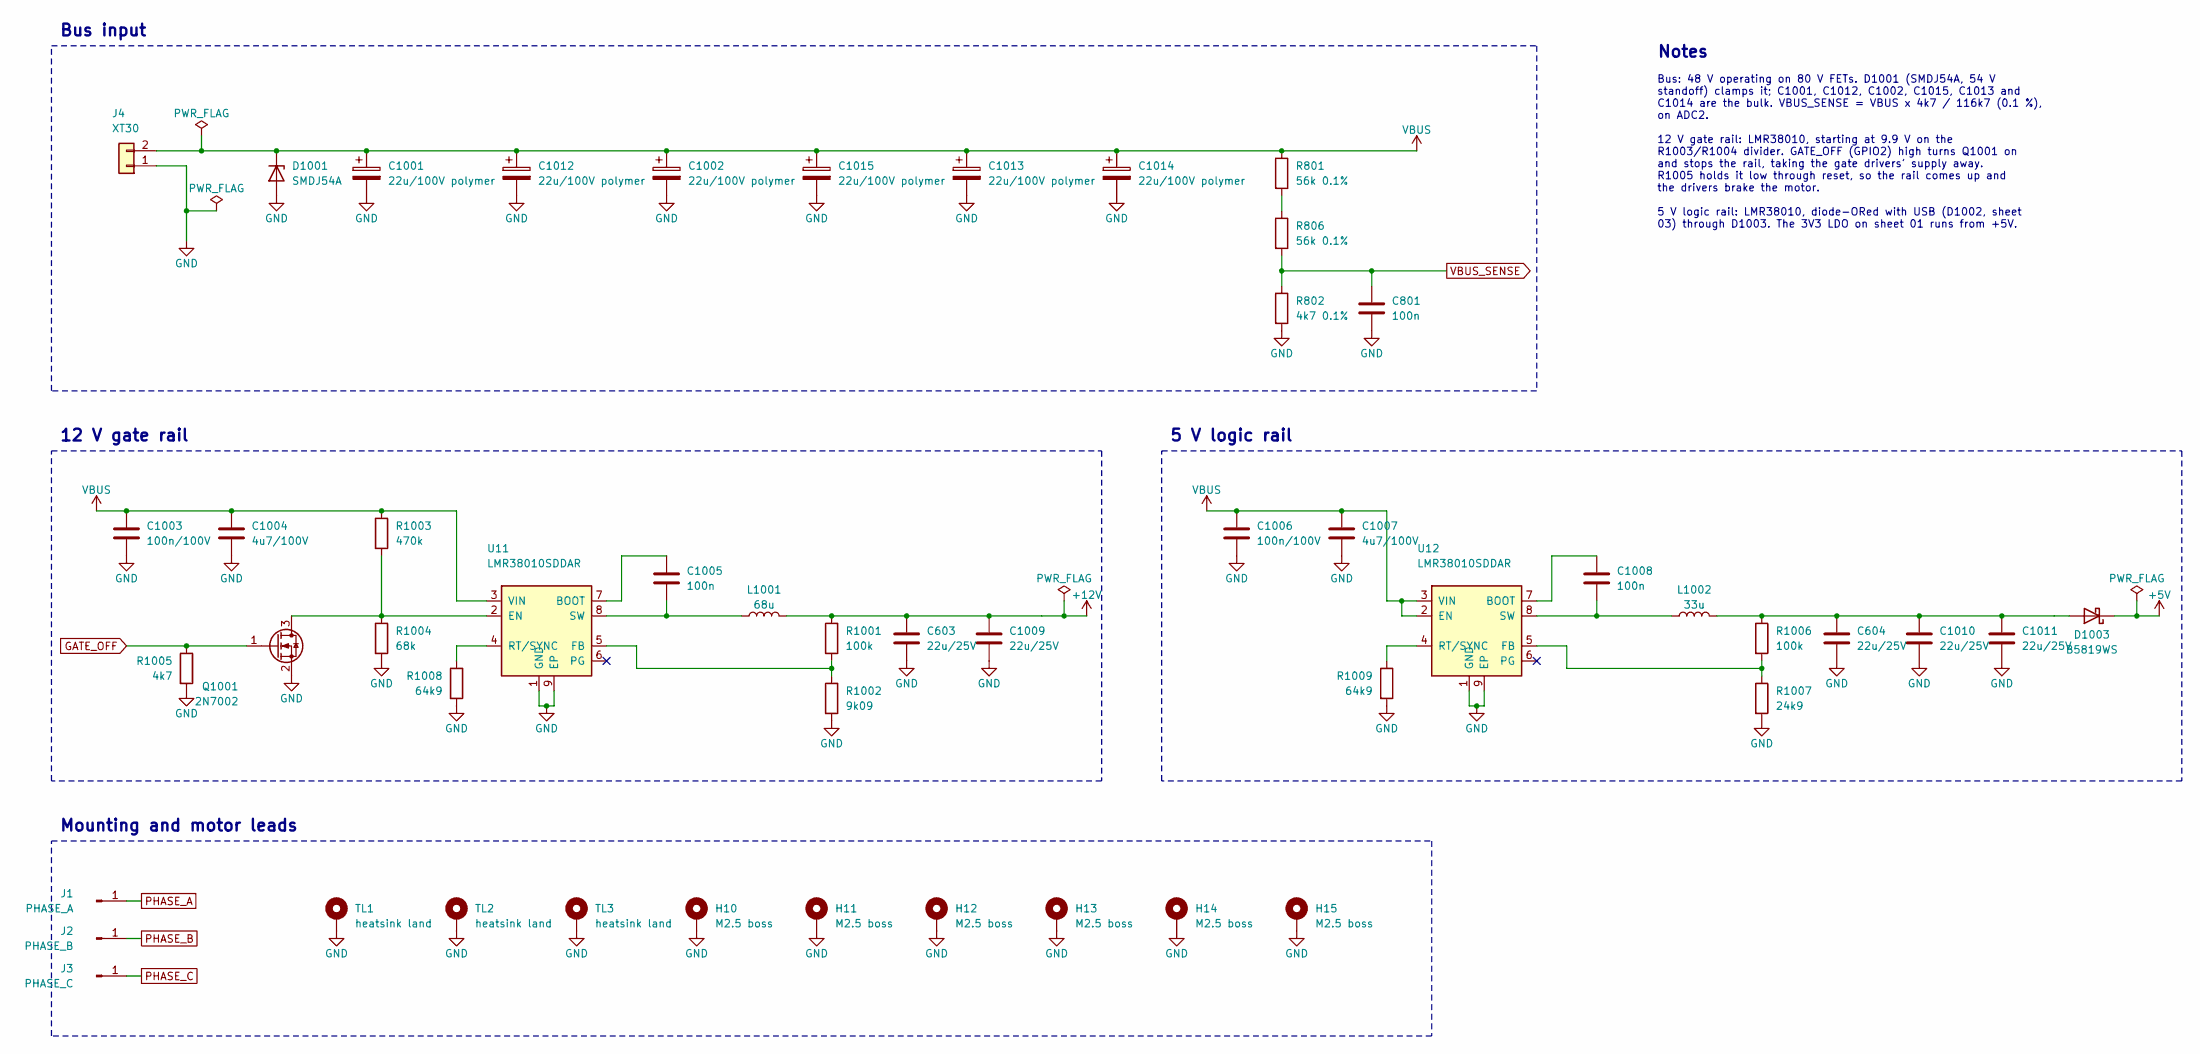
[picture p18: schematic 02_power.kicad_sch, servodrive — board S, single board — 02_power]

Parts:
C603: 22u/25V; C_1206_3216Metric
C604, C1010, C1011: 22u/25V; C_0805_2012Metric
C801: 100n; C_0603_1608Metric
C1001, C1002, C1012, C1013, C1014, C1015: 22u/100V polymer; CP_Radial_D6.3mm_P2.50mm
C1003, C1006: 100n/100V; C_0805_2012Metric
C1004, C1007: 4u7/100V; C_1206_3216Metric
C1005, C1008: 100n; C_0402_1005Metric
C1009: 22u/25V; C_1210_3225Metric
D1001: SMDJ54A; D_SMC
D1003: B5819WS; D_SOD-323
H10, H11, H12, H13, H14, H15: M2.5 boss; ThermalBoss_M2.5
J1: PHASE_A; PhasePad_Arc
J2: PHASE_B; PhasePad_Arc
J3: PHASE_C; PhasePad_Arc
J4: XT30; AMASS_XT30PW-M_1x02_P2.50mm_Horizontal
L1001: 68u; L_Sunlord_SWPA4030S
L1002: 33u; L_Sunlord_SWPA4030S
Q1001: 2N7002; SOT-23
R801, R806: 56k 0.1%; R_0603_1608Metric
R802: 4k7 0.1%; R_0603_1608Metric
R1001, R1006: 100k; R_0402_1005Metric
R1002: 9k09; R_0402_1005Metric
R1003: 470k; R_0402_1005Metric
R1004: 68k; R_0402_1005Metric
R1005: 4k7; R_0402_1005Metric
R1007: 24k9; R_0402_1005Metric
R1008, R1009: 64k9; R_0402_1005Metric
TL1, TL2, TL3: heatsink land; ThermalLand_Phase
U11, U12: LMR38010SDDAR; TI_SO-PowerPAD-8

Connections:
+5V: D1003.1 (K); also elsewhere on the board
+5V_BUCK: C604.1, C1010.1, C1011.1, D1003.2 (A), L1002.2, R1006.1
+12V: C603.1, C1009.1, L1001.2, R1001.1; also elsewhere on the board
BOOT_5V: C1008.1, U12.7 (BOOT)
BOOT_12V: C1005.1, U11.7 (BOOT)
EN_12V: Q1001.3 (D), R1003.2, R1004.1, U11.2 (EN)
FB_5V: R1006.2, R1007.1, U12.5 (FB)
FB_12V: R1001.2, R1002.1, U11.5 (FB)
GATE_OFF: Q1001.1 (G), R1005.1; also elsewhere on the board
GND: C603.2, C604.2, C801.2, C1001.2, C1002.2, C1003.2, C1004.2, C1006.2, C1007.2, C1009.2, C1010.2, C1011.2, C1012.2, C1013.2, C1014.2, C1015.2, D1001.2 (A), H10.1, H11.1, H12.1, H13.1, H14.1, H15.1, J4.1, Q1001.2 (S), R802.2, R1002.2, R1004.2, R1005.2, R1007.2, R1008.2, R1009.2, TL1.1, TL2.1, TL3.1, U11.1 (GND), U11.9 (EP), U12.1 (GND), U12.9 (EP); also elsewhere on the board
PHASE_A: J1.1; also elsewhere on the board
PHASE_B: J2.1; also elsewhere on the board
PHASE_C: J3.1; also elsewhere on the board
RT_5V: R1009.1, U12.4 (RT/SYNC)
RT_12V: R1008.1, U11.4 (RT/SYNC)
SW_5V: C1008.2, L1002.1, U12.8 (SW)
SW_12V: C1005.2, L1001.1, U11.8 (SW)
VBUS: C1001.1, C1002.1, C1003.1, C1004.1, C1006.1, C1007.1, C1012.1, C1013.1, C1014.1, C1015.1, D1001.1 (K), J4.2, R801.1, R1003.1, U11.3 (VIN), U12.2 (EN), U12.3 (VIN); also elsewhere on the board
VBUS_SENSE: C801.1, R802.1, R806.2; also elsewhere on the board
VDIV_MID: R801.2, R806.1

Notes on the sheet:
Bus input
12 V gate rail
5 V logic rail
Mounting and motor leads
Notes
Bus: 48 V operating on 80 V FETs. D1001 (SMDJ54A, 54 V standoff) clamps it; C1001, C1012, C1002, C1015, C1013 and C1014 are the bulk. VBUS_SENSE = VBUS x 4k7 / 116k7 (0.1 %), on ADC2. 12 V gate rail: LMR38010, starting at 9.9 V on the R1003/R1004 divider. GATE_OFF (GPIO2) high turns Q1001 on and st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

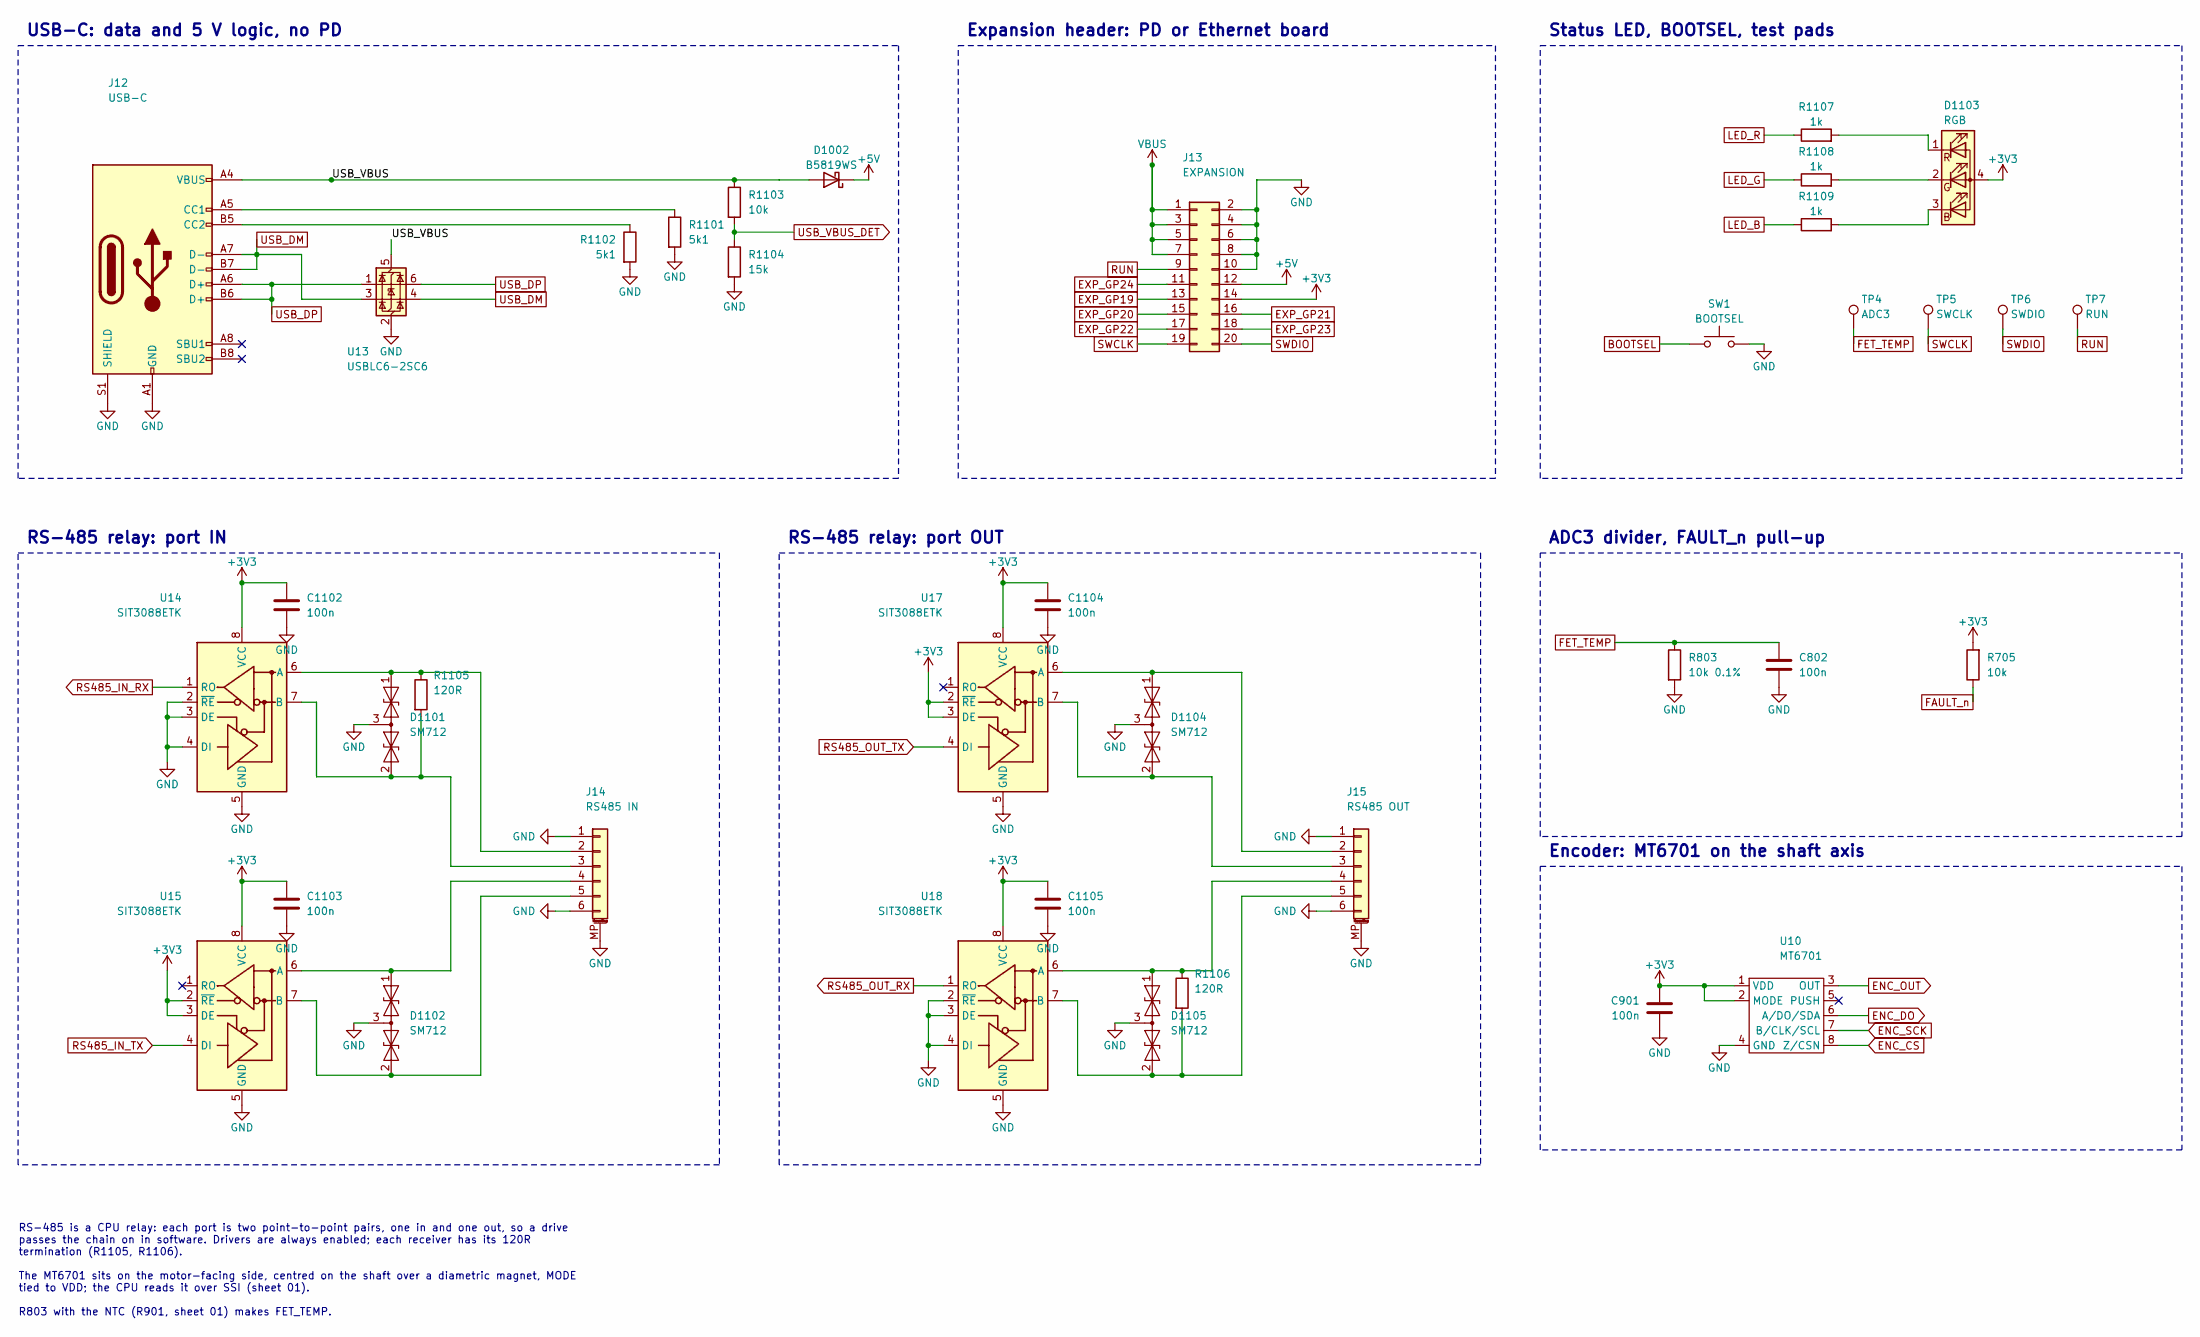
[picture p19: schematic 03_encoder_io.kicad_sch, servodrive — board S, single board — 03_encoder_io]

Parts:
C802: 100n; C_0603_1608Metric
C901, C1102, C1103, C1104, C1105: 100n; C_0402_1005Metric
D1002: B5819WS; D_SOD-323
D1101, D1102, D1104, D1105: SM712; SOT-23
D1103: RGB; LED_RGB_1210
J12: USB-C; USB_C_Receptacle_HRO_TYPE-C-31-M-12
J13: EXPANSION; PinHeader_2x10_P1.27mm_Vertical_SMD
J14: RS485 IN; JST_SH_SM06B-SRSS-TB_1x06-1MP_P1.00mm_Horizontal
J15: RS485 OUT; JST_SH_SM06B-SRSS-TB_1x06-1MP_P1.00mm_Horizontal
R705, R1103: 10k; R_0402_1005Metric
R803: 10k 0.1%; R_0603_1608Metric
R1101, R1102: 5k1; R_0402_1005Metric
R1104: 15k; R_0402_1005Metric
R1105, R1106: 120R; R_0603_1608Metric
R1107, R1108, R1109: 1k; R_0402_1005Metric
SW1: BOOTSEL; SW_SPST_B3U-1000P
TP4: ADC3; TestPoint_Pad_D1.0mm
TP5: SWCLK; TestPoint_Pad_D1.0mm
TP6: SWDIO; TestPoint_Pad_D1.0mm
TP7: RUN; TestPoint_Pad_D1.0mm
U10: MT6701; SOIC-8_3.9x4.9mm_P1.27mm
U13: USBLC6-2SC6; SOT-23-6
U14, U15, U17, U18: SIT3088ETK; DFN-8_L3.0-W3.0-P0.65-BL-EP

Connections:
+3V3: C901.1, C1102.1, C1103.1, C1104.1, C1105.1, D1103.4 (A), J13.14, R705.2, U10.1 (VDD), U10.2 (MODE), U14.8 (VCC), U15.2 (~RE), U15.3 (DE), U15.8 (VCC), U17.2 (~RE), U17.3 (DE), U17.8 (VCC), U18.8 (VCC); also elsewhere on the board
+5V: D1002.1 (K), J13.12; also elsewhere on the board
BOOTSEL: SW1.1; also elsewhere on the board
CC1: J12.A5 (CC1), R1101.1
CC2: J12.B5 (CC2), R1102.1
ENC_CS: U10.8 (Z/CSN); also elsewhere on the board
ENC_DO: U10.6 (A/DO/SDA); also elsewhere on the board
ENC_OUT: U10.3 (OUT); also elsewhere on the board
ENC_SCK: U10.7 (B/CLK/SCL); also elsewhere on the board
EXP_GP19: J13.13; also elsewhere on the board
EXP_GP20: J13.15; also elsewhere on the board
EXP_GP21: J13.16; also elsewhere on the board
EXP_GP22: J13.17; also elsewhere on the board
EXP_GP23: J13.18; also elsewhere on the board
EXP_GP24: J13.11; also elsewhere on the board
FAULT_n: R705.1; also elsewhere on the board
FET_TEMP: C802.1, R803.1, TP4.1; also elsewhere on the board
GND: C802.2, C901.2, C1102.2, C1103.2, C1104.2, C1105.2, D1101.3 (common), D1102.3 (common), D1104.3 (common), D1105.3 (common), J12.A1 (GND), J12.A12 (GND), J12.B1 (GND), J12.B12 (GND), J12.S1 (SHIELD), J13.2, J13.4, J13.6, J13.8, J13.10, J14.1, J14.6, J14.MP (MountPin), J15.1, J15.6, J15.MP (MountPin), R803.2, R1101.2, R1102.2, R1104.2, SW1.2, U10.4 (GND), U13.2 (GND), U14.2 (~RE), U14.3 (DE), U14.4 (DI), U14.5 (GND), U15.5 (GND), U17.5 (GND), U18.2 (~RE), U18.3 (DE), U18.4 (DI), U18.5 (GND); also elsewhere on the board
LED_B: R1109.1; also elsewhere on the board
LED_B_K: D1103.3 (BK), R1109.2
LED_G: R1108.1; also elsewhere on the board
LED_G_K: D1103.2 (GK), R1108.2
LED_R: R1107.1; also elsewhere on the board
LED_R_K: D1103.1 (RK), R1107.2
RS485_IN_DN_N: D1101.2 (A2), J14.3, R1105.2, U14.7 (B)
RS485_IN_DN_P: D1101.1 (A1), J14.2, R1105.1, U14.6 (A)
RS485_IN_RX: U14.1 (RO); also elsewhere on the board
RS485_IN_TX: U15.4 (DI); also elsewhere on the board
RS485_IN_UP_N: D1102.2 (A2), J14.5, U15.7 (B)
RS485_IN_UP_P: D1102.1 (A1), J14.4, U15.6 (A)
RS485_OUT_DN_N: D1104.2 (A2), J15.3, U17.7 (B)
RS485_OUT_DN_P: D1104.1 (A1), J15.2, U17.6 (A)
RS485_OUT_RX: U18.1 (RO); also elsewhere on the board
RS485_OUT_TX: U17.4 (DI); also elsewhere on the board
RS485_OUT_UP_N: D1105.2 (A2), J15.5, R1106.2, U18.7 (B)
RS485_OUT_UP_P: D1105.1 (A1), J15.4, R1106.1, U18.6 (A)
RUN: J13.9, TP7.1; also elsewhere on the board
SWCLK: J13.19, TP5.1; also elsewhere on the board
SWDIO: J13.20, TP6.1; also elsewhere on the board
USB_DM: J12.A7 (D-), J12.B7 (D-), U13.3 (I/O2), U13.4 (I/O2); also elsewhere on the board
USB_DP: J12.A6 (D+), J12.B6 (D+), U13.1 (I/O1), U13.6 (I/O1); also elsewhere on the board
USB_VBUS: D1002.2 (A), J12.A4 (VBUS), J12.A9 (VBUS), J12.B4 (VBUS), J12.B9 (VBUS), R1103.1, U13.5 (VBUS)
USB_VBUS_DET: R1103.2, R1104.1; also elsewhere on the board
VBUS: J13.1, J13.3, J13.5, J13.7; also elsewhere on the board

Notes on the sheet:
USB-C: data and 5 V logic, no PD
RS-485 relay: port IN
RS-485 relay: port OUT
Expansion header: PD or Ethernet board
Status LED, BOOTSEL, test pads
ADC3 divider, FAULT_n pull-up
Encoder: MT6701 on the shaft axis
RS-485 is a CPU relay: each port is two point-to-point pairs, one in and one out, so a drive passes the chain on in software. Drivers are always enabled; each receiver has its 120R termination (R1105, R1106). The MT6701 sits on the motor-facing side, centred on the shaft over a diametric magnet, MO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

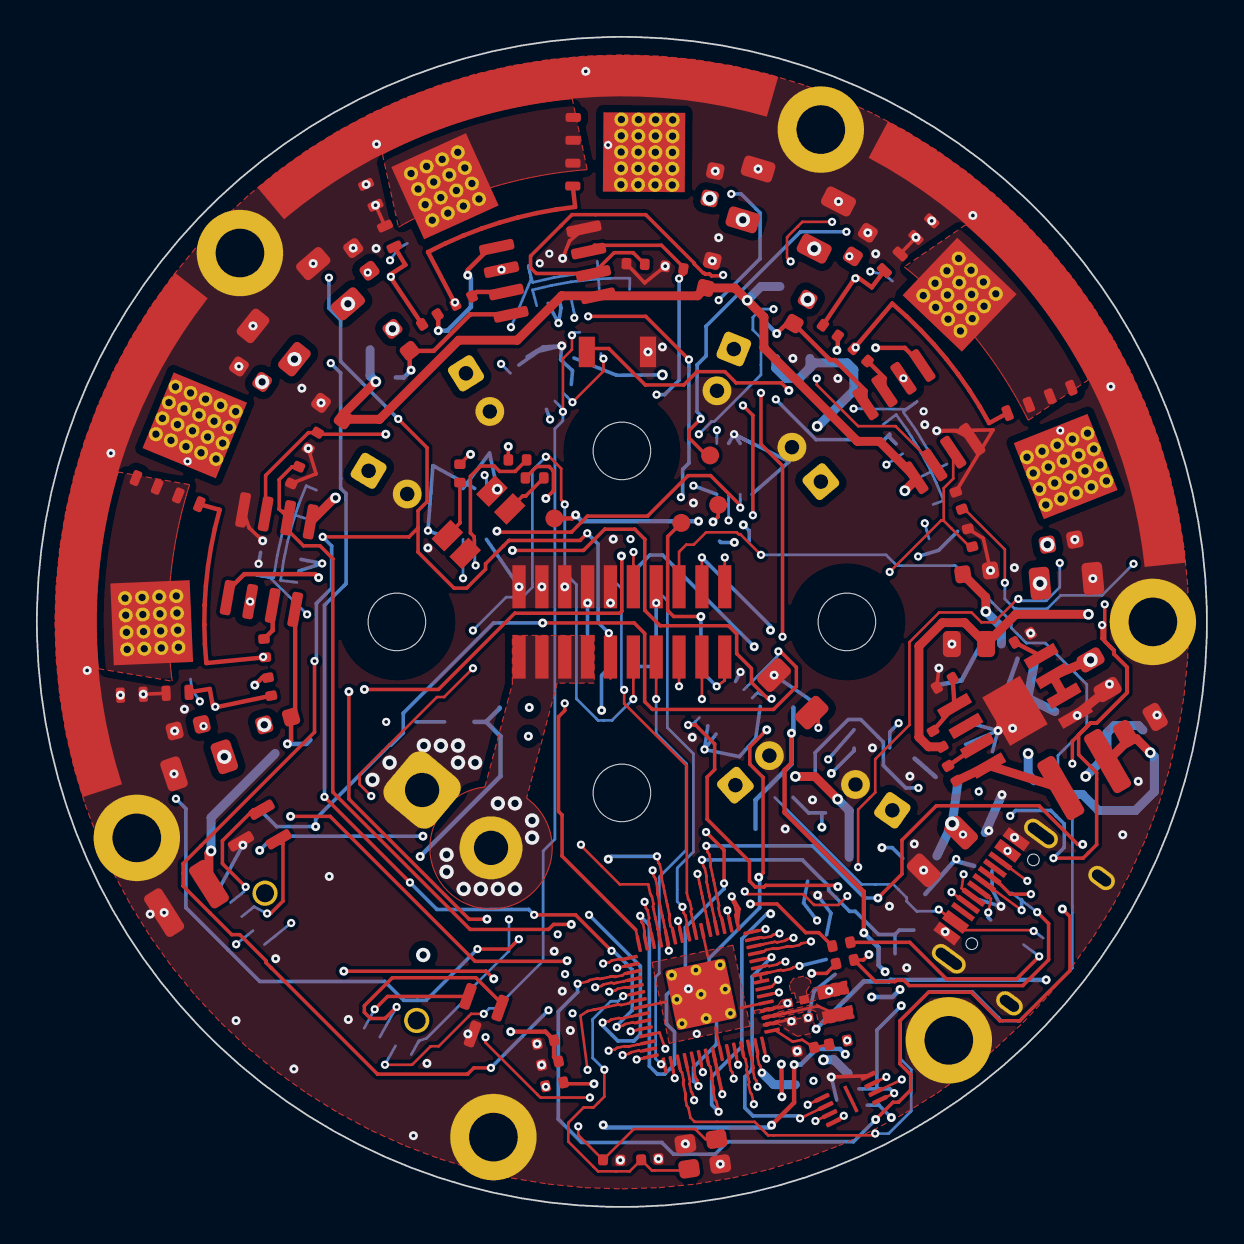
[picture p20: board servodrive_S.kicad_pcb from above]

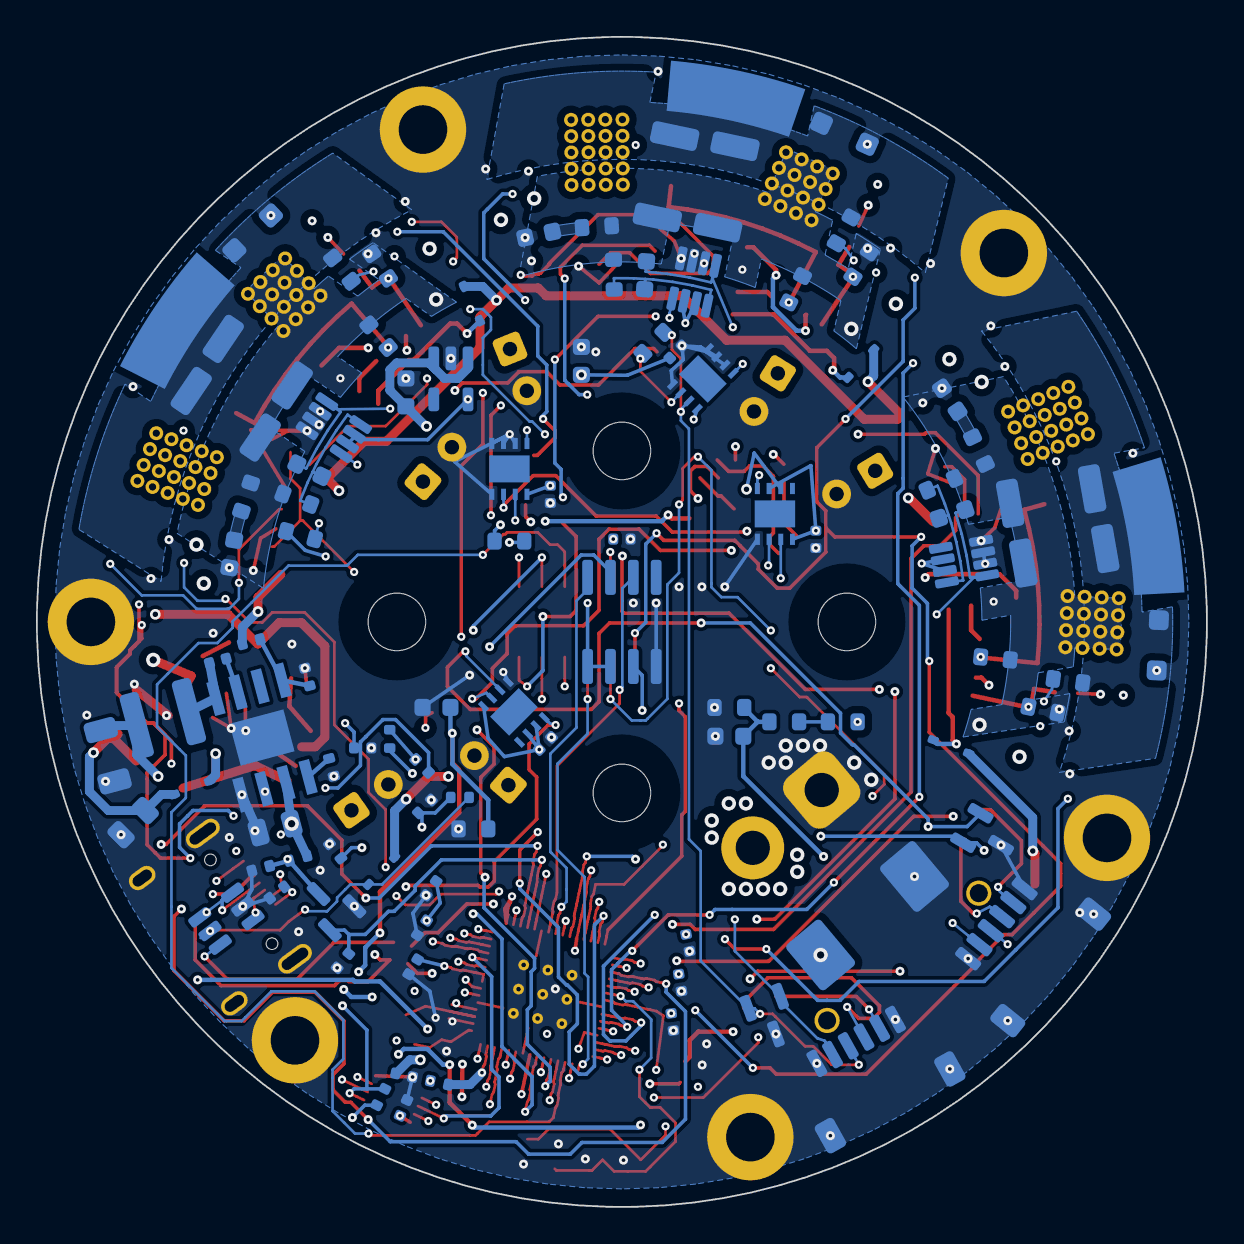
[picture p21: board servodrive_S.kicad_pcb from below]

Board: 6 copper layers, 65.0 x 65.0 mm, 198 parts (99 on the bottom side), 111 nets.

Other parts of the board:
H1, H2, H3, H4: MountingHole_3.2mm_M3

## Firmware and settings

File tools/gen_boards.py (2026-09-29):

#!/usr/bin/env python3
"""gen_boards.py — emit the servodrive KiCad projects from tools/geometry.py.

The board outlines, the motor mount pattern and the perimeter bolt circle are
not things to draw by hand twice. They come from geometry.py, which is also what
the spec quotes, so the boards and the prose cannot disagree.

    python3 tools/gen_boards.py            # create anything missing
    python3 tools/gen_boards.py --force    # overwrite, DESTROYS layout work

Refuses to overwrite an existing .kicad_pcb or .kicad_sch without --force: once
you have placed a part, this script is no longer the source of truth for that
file and re-running it would throw the work away.
"""
import argparse, json, os, re, shutil, uuid
from math import cos, sin, radians, tau
from pathlib import Path

import geometry as G
import placement as PL
import sexp
import schematic as SCH
import schlayout_s as SCHL
import stitch
import fanout

ROOT = Path(__file__).resolve().parent.parent
HW   = ROOT / "hardware"

# Deterministic UUIDs, so re-running produces byte-identical files.
NS = uuid.UUID("6f2a1c44-0000-4000-8000-000000000000")
def uid(*parts): return str(uuid.uuid5(NS, "/".join(str(p) for p in parts)))

# KiCad places the origin at the sheet's top-left; put the board centre here.
CX, CY = 148.0, 105.0
def P(x, y):
    """geometry.py coords (y up, origin at the shaft) -> KiCad page coords."""
    return (CX + x, CY - y)

# ---------------------------------------------------------------- boards ----
BOARDS = {
    "motor_board": dict(
        name="servodrive_A", title="servodrive — board A, motor board",
        layers=6, copper=["F.Cu", "In1.Cu", "In2.Cu", "In3.Cu", "In4.Cu", "B.Cu"],
        motor_mount=True,
        note=("MT6701 at (0,0) on the MOTOR-FACING side. Bridge, drivers, "
              "shunts, RP2350A and the DC-link ceramics on the outward side."),
    ),
    # Board S: board A and the minimum of board B on one board (2026-09-22).
    # Same stack, same mount, same cells and CPU; the two link wedges and the
    # centre carry what board B would have. Emitted only by --board s.
    "single_board": dict(
        name="servodrive_S", title="servodrive — board S, single board",
        layers=6, copper=["F.Cu", "In1.Cu", "In2.Cu", "In3.Cu", "In4.Cu", "B.Cu"],
        motor_mount=True, variant="s",
        note=("Board A plus the minimum of board B. 48 V max. XT30 bus input, TVS and "
              "cans, two LMR38010 rails, USB-C, RS-485 relay on two SH 6, expansion header."),
        # the root sheet's comments: board S's sheets are drawn, not a skeleton
        comments=("Sheets drawn by tools/schlayout_s.py from the netlist in tools/schematic_s.py",
                  "See ../../single.html"),
    ),
    "power_board": dict(
        name="servodrive_B", title="servodrive — board B, power / IO",
        layers=4, copper=["F.Cu", "In1.Cu", "In2.Cu", "B.Cu"],
        motor_mount=False,
        note=("Mounts on the six perimeter M2.5. Bus input, ideal diode, TVS, "
              "bulk, two LMR38010 rails, FUSB302 PD, two RS-485 ports."),
    ),
}

LAYER_IDS = {"F.Cu": 0, "B.Cu": 2, "In1.Cu": 4, "In2.Cu": 6, "In3.Cu": 8, "In4.Cu": 10}
USER_LAYERS = '''		(9 "F.Adhes" user "F.Adhesive")
		(11 "B.Adhes" user "B.Adhesive")
		(13 "F.Paste" user)
		(15 "B.Paste" user)
		(5 "F.SilkS" user "F.Silkscreen")
		(7 "B.SilkS" user "B.Silkscreen")
		(1 "F.Mask" user)
		(3 "B.Mask" user)
		(17 "Dwgs.User" user "User.Drawings")
		(19 "Cmts.User" user "User.Comments")
		(21 "Eco1.User" user "User.Eco1")
		(23 "Eco2.User" user "User.Eco2")
		(25 "Edge.Cuts" user)
		(27 "Margin" user)
		(31 "F.CrtYd" user "F.Courtyard")
		(29 "B.CrtYd" user "B.Courtyard")
		(35 "F.Fab" user)
		(33 "B.Fab" user)'''

def stackup(copper):
    """2 oz outers, 1 oz inners, 1.6 mm overall — same recipe as the sister board."""
    out = ['\t\t(stackup',
           '\t\t\t(layer "F.SilkS" (type "Top Silk Screen"))',
           '\t\t\t(layer "F.Paste" (type "Top Solder Paste"))',
           '\t\t\t(layer "F.Mask" (type "Top Solder Mask") (thickness 0.01))']
    n = len(copper)
    # Dielectrics sized so the stack really does land on 1.6 mm: copper
    # (2 x 0.07 outer + (n-2) x 0.035 inner) + masks (2 x 0.01) + prepreg
    # (2 x 0.1) + cores. The 0.1 mm outer prepreg is not a rounding choice --
    # it is what puts the In1 ground plane 0.1 mm under the commutation loop,
    # and geometry.commutation_loop() is quoted at that number.
    PREPREG, MASK = 0.10, 0.01
    cu = 2 * 0.07 + (n - 2) * 0.035
    core = (1.6 - cu - 2 * MASK - 2 * PREPREG) / (n - 3)
    d = 0
    for i, cu in enumerate(copper):
        th = 0.07 if cu in ("F.Cu", "B.Cu") else 0.035
        out.append(f'\t\t\t(layer "{cu}" (type "copper") (thickness {th}))')
        if i < n - 1:
            d += 1
            t = PREPREG if (i == 0 or i == n - 2) else core
            kind = "prepreg" if (i == 0 or i == n - 2) else "core"
            out.append(f'\t\t\t(layer "dielectric {d}" (type "{kind}") (thickness {t}) '
                       f'(material "FR4") (epsilon_r 4.5) (loss_tangent 0.02))')
    out += ['\t\t\t(layer "B.Mask" (type "Bottom Solder Mask") (thickness 0.01))',
            '\t\t\t(layer "B.Paste" (type "Bottom Solder Paste"))',
            '\t\t\t(layer "B.SilkS" (type "Bottom Silk Screen"))',
            '\t\t\t(copper_finish "None")',
            '\t\t\t(dielectric_constraints yes)',
            '\t\t)']
    return "\n".join(out)

# ------------------------------------------------------------- variants ----
# Board A and board S come out of the same functions. Which netlist and which
# placement they read is the ACTIVE variant, set by board() and main(); board
# A is the default, so nothing that did not ask for S sees anything new.
def _s_comps():
    import schematic_s
    return schematic_s.board_s()

def _s_parts():
    import placement_s
    return placement_s.parts()

VARIANTS = {"a": dict(comps=SCH.board_a, parts=PL.board_a),
            "s": dict(comps=_s_comps, parts=_s_parts)}
_ACTIVE = "a"
_CACHE = {}

def use(variant):
    global _ACTIVE
    _ACTIVE = variant

def comps():
    """The active variant's netlist (schematic.Comp)."""
    key = ("comps", _ACTIVE)
    if key not in _CACHE:
        _CACHE[key] = VARIANTS[_ACTIVE]["comps"]()
    return _CACHE[key]

def placed():
    """The active variant's placement (placement.Part). On board S the
    netlist's value wins: the sketch's parts carry the sketch's values."""
    key = ("parts", _ACTIVE)
    if key not in _CACHE:
        ps = VARIANTS[_ACTIVE]["parts"]()
        if _ACTIVE != "a":
            val = {c.ref: c.value for c in comps()}
            for p in ps:
                p.value = val.get(p.ref, p.value)
        _CACHE[key] = ps
    return _CACHE[key]

def net_table():
    """{name: index} for the whole board. Index 0 is the no-net net.

    A board with no nets is not routable and DRC on it proves nothing: every
    pad is its own island, so clearance checks fire between pins of the same
    part and shorts between different ones go unnoticed. The netlist is in
    schematic.py; this is how it reaches the copper.
    """
    key = ("nets", _ACTIVE)
    if key not in _CACHE:
        names = sorted({n for c in comps() for n in c.nets.values() if n})
        t = {"": 0}
        t.update({n: i + 1 for i, n in enumerate(names)})
        _CACHE[key] = t
    return _CACHE[key]

def pad_nets(ref):
    """{pad number: net name} for one reference, from the netlist."""
    for c in comps():
        if c.ref == ref:
            return c.nets
    return {}

def _apply_nets(body, nets):
    """Put (net ...) on every pad the netlist has an entry for."""
    if not nets:
        return body
    table = net_table()
    for a, b in sorted(_blocks(body, "pad"), reverse=True):
        blk = body[a:b]
        num = re.match(r'\(pad\s+"([^"]*)"', blk)
        if not num:
            continue
        net = nets.get(num.group(1))
        if not net:
            continue
        m = re.search(r'\(layers[^)]*\)', blk)
        if not m:
            continue
        blk = (blk[:m.end()]
               + f'\n\t\t(net {table[net]} "{net}")'
               + blk[m.end():])
        body = body[:a] + blk + body[b:]
    return body

def embed(fp_path, lib, name, ref, x, y, ang=0.0, layer="F.Cu", value=None,
          note="", tag="", dnp=False, nets=None):
    """Put one library footprint on a board, at a position and an angle.

    Everything placed on either board goes through here -- parts, mounting
    holes, heatsink lands, phase pads. It used to be two near-identical
    functions and they drifted: the second one never learned to flip, and three
    motor-lead pads spent a build on the wrong side of the board.

    DRC compares every board footprint against its library copy, so the library
    body is what goes in, edited as little as possible: the designator, the
    value, the layer, and nothing else.
    """
    src = Path(fp_path).read_text()
    body = src[src.index("\n", src.index('(footprint "')) + 1:].rstrip()
    assert body.endswith(")"), f"{name}: unexpected footprint file shape"
    body = body[:-1].rstrip()
    for pat in (r'\t\(version \d+\)\n', r'\t\(generator "[^"]*"\)\n',
                r'\t\(generator_version "[^"]*"\)\n', r'\t\(layer "F\.Cu"\)\n'):
        body = re.sub(pat, "", body, count=1)
    body = set_property(body, "Reference", ref, "F.Fab")
    if value is not None:
        body = set_property(body, "Value", value)
    if dnp:
        # DNP is an attribute token on a board footprint, not its own
        # s-expression: "(dnp yes)" parses in a schematic and fails here.
        if re.search(r'^\t\(attr [^)]*\)', body, re.M):
            body = re.sub(r'^(\t\(attr [^)]*)\)', r'\1 dnp)', body, count=1, flags=re.M)
        else:
            body = "\t(attr dnp)\n" + body
    body = strip_silk(body)
    if layer == "B.Cu":
        body = _flip(body)
    # after the flip, not before: flipping negates any angle it finds, and the
    # angle a custom pad needs is the footprint's own, on either side.
    body = rotate_pads(body, ang)
    body = _apply_nets(body, nets)
    # Every uuid inside the library body is the library's, so two instances
    # of one footprint share them; KiCad's DRC report then looks an item up
    # by uuid and describes the wrong footprint's pad. One per instance.
    k = [0]
    def fresh(m):
        k[0] += 1
        return f'(uuid "{uid(tag, ref, "item", k[0])}")'
    body = re.sub(r'\(uuid "[0-9a-fA-F-]+"\)', fresh, body)
    body = "\n".join(("\t" + ln) if ln.strip() else ln for ln in body.split("\n"))
    px, py = P(x, y)
    fab = "B.Fab" if layer == "B.Cu" else "F.Fab"
    return (f'\t(footprint "{lib}:{name}"\n'
            f'\t\t(layer "{layer}")\n'
            f'\t\t(uuid "{uid(tag, ref, "fp")}")\n'
            f'\t\t(at {px:.4f} {py:.4f} {ang:.3f})\n'
            f'\t\t(property "servodrive_role" "{note}"\n'
            f'\t\t\t(at 0 0 0) (layer "{fab}") (hide yes) '
            f'(uuid "{uid(tag, ref, "role")}")\n'
            f'\t\t\t(effects (font (size 0.6 0.6) (thickness 0.1))))\n'
            f'{body}\n\t)')

KFP      = Path("/usr/share/kicad/footprints")
STOCK_FP = KFP / "MountingHole.pretty"
PROJ_FP  = HW / "parts/servodrive.pretty"

def mounting_hole(ref, fp_name, x, y, tag, desc, src_dir=None,
                  lib="MountingHole", rot=0.0, layer="F.Cu"):
    """A hole, a heatsink land or a phase pad: geometry with no schematic."""
    return embed((src_dir or STOCK_FP) / f"{fp_name}.kicad_mod", lib, fp_name,
                 ref, x, y, rot, layer, note=desc, tag=tag, nets=pad_nets(ref))

# ------------------------------------------------ derived footprints ----
# Three footprints this design needs that no library has. They are GENERATED,
# from the same constants as everything else, so the thermal via pitch and the
# ring land cannot drift from geometry.py's thermal model.

def _fp_head(name, descr, ref_prefix, extra_attr="smd exclude_from_pos_files"):
    return (f'(footprint "{name}"\n'
            f'\t(version 20241229)\n'
            f'\t(generator "servodrive/tools/gen_boards.py")\n'
            f'\t(layer "F.Cu")\n'
            f'\t(descr "{descr}")\n'
            f'\t(tags "servodrive thermal")\n'
            f'\t(attr {extra_attr})\n'
            f'\t(property "Reference" "{ref_prefix}**"\n'
            f'\t\t(at 0 0 0) (layer "F.Fab")\n'
            f'\t\t(effects (font (size 1 1) (thickness 0.15))))\n'
            f'\t(property "Value" "{name}"\n'
            f'\t\t(at 0 1.6 0) (layer "F.Fab")\n'
            f'\t\t(effects (font (size 0.8 0.8) (thickness 0.12))))\n')

def fet_thermal_vias(ny=None, pitch_y=None, shift=0.0, name="TDSON-8-1_ThermalVias"):
    """TDSON-8-1 with a via array in the drain pad.

    KiCad ships both the symbol for this exact MOSFET and the footprint its
    pin numbering assumes, so both come from there: pads 1-3 source, 4 gate,
    5 drain. The sister project's PowerPAK_SO-8_123 numbers them 1/2/3 =
    S/G/D, which no stock symbol matches -- a mismatch waiting to be wired
    backwards.

    The array is what gets the FET's 1.6 W into the inner copper, and the
    phase current through the board: geometry.via_thermal() puts 16 barrels
    of 0.4 mm at 7.6 K/W, against 354 K/W for the FR4 on its own. The pitch
    is set by the 0.5 mm hole-to-hole rule the project adopted so JLCPCB's
    free via-in-pad stays available (their F-48). The high side takes a
    fifth row (FET_VIA_NY_HS) -- see geometry.py for why only it can.
    """
    src = (KFP / "Package_TO_SOT_SMD.pretty" / "TDSON-8-1.kicad_mod").read_text()
    PAD_C, PAD_W, PAD_H = 1.05, 4.55, 4.41        # drain pad, from the library
    nx = G.FET_VIA_NX
    ny = G.FET_VIA_NY if ny is None else ny
    px = G.FET_VIA_PITCH
    py = G.FET_VIA_PITCH if pitch_y is None else pitch_y
    vias, k = [], 0
    for i in range(nx):
        for j in range(ny):
            dx = (i - (nx - 1) / 2) * px + shift
            dy = (j - (ny - 1) / 2) * py
            assert abs(dx) + G.VIA_PAD / 2 <= PAD_W / 2, "via array too wide"
            assert abs(dy) + G.VIA_PAD / 2 <= PAD_H / 2, "via array too tall"
            assert min(px, py) - G.VIA_DRILL >= 0.5, "inside the 0.5 mm hole-to-hole rule"
            k += 1
            vias.append(
                f'\t(pad "5" thru_hole circle\n'
                f'\t\t(at {PAD_C + dx:.4f} {dy:.4f})\n'
                f'\t\t(size {G.VIA_PAD} {G.VIA_PAD})\n'
                f'\t\t(drill {G.VIA_DRILL})\n'
                f'\t\t(layers "*.Cu")\n'
                f'\t\t(remove_unused_layers no)\n'
                f'\t\t(zone_connect 2)\n'
                f'\t)')
    out = src.replace('(footprint "TDSON-8-1"', f'(footprint "{name}"', 1)
    out = re.sub(r'\(descr "([^"]*)"',
                 lambda m: f'(descr "{m.group(1)} - plus a {k}-via thermal array in the '
                           f'drain pad, {nx} x {ny} at {px} x {py} mm '
                           f'({min(px, py) - G.VIA_DRILL:.3f} mm hole-to-hole)"',
                 out, count=1)
    i = out.rstrip().rfind(")")
    return out[:i] + "\n".join(vias) + "\n" + out[i:]

def fet_thermal_vias_hs():
    """The high side's: a fifth row of barrels at 0.905 mm, and the array
    moved 0.15 mm off the source side of the pad."""
    return fet_thermal_vias(G.FET_VIA_NY_HS, G.FET_VIA_PITCH_HS, G.FET_VIA_SHIFT_HS,
                            "TDSON-8-1_ThermalVias_HS")

def thermal_boss():
    """M2.5 perimeter hole as a plated, mask-free boss on every layer.

    Six of these are where board A's heat leaves for the aluminium ring, and
    they are also what ties the ring to GND. 4.8 mm keeps 0.6 mm to the edge.
    """
    D, PAD = G.PERIM_D, 4.8
    assert G.PERIM_BC / 2 + PAD / 2 <= G.R - 0.3, "boss pad too close to the edge"
    return (_fp_head("ThermalBoss_M2.5",
                     f"M2.5 clearance hole, plated, {PAD} mm pad on every layer with "
                     f"solder mask open both sides: the standoff/heatsink joint",
                     "H", "exclude_from_pos_files")
            + f'\t(pad "1" thru_hole circle\n'
              f'\t\t(at 0 0)\n'
              f'\t\t(size {PAD} {PAD})\n'
              f'\t\t(drill {D})\n'
              f'\t\t(layers "*.Cu" "*.Mask")\n'
              f'\t\t(remove_unused_layers no)\n'
              f'\t\t(zone_connect 2)\n'
              f'\t)\n'
              f'\t(fp_circle (center 0 0) (end {PAD/2 + 0.25:.3f} 0)\n'
              f'\t\t(stroke (width 0.05) (type solid)) (fill no) (layer "F.CrtYd"))\n'
              f'\t(fp_circle (center 0 0) (end {PAD/2 + 0.25:.3f} 0)\n'
              f'\t\t(stroke (width 0.05) (type solid)) (fill no) (layer "B.CrtYd"))\n'
              f')\n')

def sector_pad(name, r0, r1, half, descr, ref_prefix):
    """A single pad shaped as an annular sector, origin at its mid-radius.

    Both of the big pads on this board are arcs, for the same reason: a
    straight pad wide enough to be useful, placed near R 30 on a R 32.5 board,
    puts its corners off the edge. An arc follows the board instead.
    """
    rm = (r0 + r1) / 2
    pts, N = [], 24
    for k in range(N + 1):                              # outer arc
        a = radians(-half + 2 * half * k / N)
        pts.append((r1 * cos(a) - rm, r1 * sin(a)))
    for k in range(N + 1):                              # inner arc, back
        a = radians(half - 2 * half * k / N)
        pts.append((r0 * cos(a) - rm, r0 * sin(a)))
    poly = " ".join(f"(xy {x:.4f} {y:.4f})" for x, y in pts)
    area = radians(2 * half) / 2 * (r1**2 - r0**2)
    return (_fp_head(name, f"{descr} R {r0}-{r1} mm over {2*half:.0f} deg, "
                           f"{area:.0f} mm2, solder mask open. Origin at the "
                           f"mid-radius on the block axis.", ref_prefix)
            + f'\t(fp_poly (pts {poly})\n'
              f'\t\t(stroke (width 0.05) (type solid)) (fill no) (layer "F.CrtYd"))\n'
              f'\t(pad "1" smd custom\n'
              f'\t\t(at 0 0)\n'
              f'\t\t(size 1 1)\n'
              f'\t\t(layers "F.Cu" "F.Mask")\n'
              f'\t\t(zone_connect 2)\n'
              f'\t\t(options (clearance outline) (anchor circle))\n'
              f'\t\t(primitives\n'
              f'\t\t\t(gr_poly (pts {poly}) (width 0) (fill yes))\n'
              f'\t\t)\n'
              f'\t)\n'
              f')\n'), area

def thermal_land():
    """The bare copper each phase cell offers the aluminium heatsink ring.

    One arc per cell, between that cell's two perimeter bolts. With the six
    bosses this is the area geometry.thermal()'s 0.4 K/W joint assumes, and it
    is the whole reason the parts inside stop at R 29.2.
    """
    return sector_pad("ThermalLand_Phase", PL.R_RING_ID, PL.R_RING_OD,
                      PL.RING_HALF, "Bare-copper heatsink land,", "TL")[0]

def phase_pad():
    """Where a motor lead lands, on the motor-facing side."""
    return sector_pad("PhasePad_Arc", PL.PAD_R0, PL.PAD_R1, PL.PAD_HALF,
                      "Motor phase lead pad, 14 AWG,", "J")[0]

# Board S's bus input: two arc pads on the outward face at the power wedge's
# rim, a 14 AWG lead soldered flat to each (placement_s.BUS_PADS). They carry
# the whole bus current into the planes, so each takes a field of barrels --
# but not in the footprint: the RS-485 ports sit on the same stretch of rim
# on the other face, and a fixed array came through onto J14's MP pad. The
# fan-out drills them where the far face leaves room (fanout.bus_field).
BUS_R0, BUS_R1, BUS_HALF = 28.7, 31.4, 3.8

def bus_pad():
    return sector_pad("BusPad_Arc", BUS_R0, BUS_R1, BUS_HALF,
                      "Bus lead pad, 14 AWG, barrels drilled by fanout.bus_field,", "J")[0]

# Board S's bus input (2026-09-24): KiCad 9's own AMASS XT30PW-M, the
# footprint the rp2350-motor-controller's J9 uses -- same pads, holes, silk
# and model -- with its courtyard drawn round the part rather than round
# its bounding box. The library's is a 14.3 x 15.9 mm rectangle to take the
# peg ears 3.6 mm behind the mouth, and its empty corners are where the SM712s
# and the 12 V rail's second cap sit; this one is the outline placement_s
# places it by: the housing and the pins, 0.25 round, and a round ear at each
# peg (EAR_R).
XT30_STOCK = Path("/usr/share/kicad/footprints/Connector_AMASS.pretty/"
                  "AMASS_XT30PW-M_1x02_P2.50mm_Horizontal.kicad_mod")

def xt30_body():
    from shapely.geometry import box, Point
    from shapely.ops import unary_union
    t = XT30_STOCK.read_text()
    for a, b in reversed(_blocks(t, "fp_line")):
        if '"F.CrtYd"' in t[a:b]:
            t = t[:a].rstrip(" \t") + t[b:].lstrip("\n")
            t = t.replace("\n\n", "\n")
    ear = 1.11 + 0.35
    body = unary_union([box(-7.81, -13.6, 2.81, 2.0), Point(-8, -10).buffer(ear, 8),
                        Point(3, -10).buffer(ear, 8)]).simplify(0.01)
    pts = " ".join(f"(xy {x:.3f} {y:.3f})" for x, y in list(body.exterior.coords)[:-1])
    poly = ('\t(fp_poly\n\t\t(pts ' + pts + ')\n\t\t(stroke (width 0.05) (type solid))\n'
            '\t\t(fill no)\n\t\t(layer "F.CrtYd")\n\t\t(uuid "' + uid("xt30", "crtyd") + '")\n\t)\n')
    i = t.index("\t(pad ")
    t = t[:i] + poly + t[i:]
    return t.replace('(descr "Connector XT30 Horizontal PCB Male,',
                     '(descr "Connector XT30 Horizontal PCB Male, KiCad 9\'s footprint with its '
                     'courtyard round the housing, pins and peg ears (servodrive),', 1)

# ------------------------------------------------- placing footprints ----
BACK = {"F.Cu": "B.Cu", "F.Paste": "B.Paste", "F.Mask": "B.Mask",
        "F.SilkS": "B.SilkS", "F.CrtYd": "B.CrtYd", "F.Fab": "B.Fab"}
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

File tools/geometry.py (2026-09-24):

#!/usr/bin/env python3
"""geometry.py — the servodrive board geometry, in one place, and the SVGs that draw it.

Every dimension the spec quotes comes from here. Re-run to regenerate img/*.svg
after changing a number, so the drawings and the prose can never drift apart.

    python3 tools/geometry.py

Coordinates are millimetres, origin at the motor shaft axis (= the MT6701's
sensing centre). Plan views are TOP views: +x right, +y up. SVG y is flipped on
emit.
"""
from math import cos, sin, radians
from pathlib import Path

OUT = Path(__file__).resolve().parent.parent / "img"

# ---------------------------------------------------------------- geometry --
DIA          = 65.0          # both boards, outer diameter
R            = DIA / 2       # 32.5
EDGE_CLEAR   = 1.0           # copper pullback from the edge
R_USABLE     = R - EDGE_CLEAR

# Motor mount — inherited verbatim from rp2350-motor-controller/hardware/encoder.
# Four M3, centred on the sensor, in two orthogonal pairs at different spacings.
MOUNT_X      = 12.5          # holes at (+-12.5, 0)
MOUNT_Y      = 9.5           # holes at (0, +-9.5)
MOUNT_D      = 3.2           # clearance for M3
MOUNT_HEAD   = 6.5           # screw-head / washer keepout diameter
R_CENTRE     = 16.0          # everything inside this radius belongs to the
                             # encoder + motor mount; no other parts

# Sections. The three phase cells are ADJACENT, and the three utility wedges
# with them, rather than the two kinds alternating. Three reasons, in order:
#
#   - the CPU stops sitting between two switching cells. In the alternating
#     layout the RP2350A had a half-bridge 25 deg away on each side; grouped,
#     it sits in the middle wedge, as far from all three as the board allows.
#   - the three motor leads leave together, so one bundle leaves the enclosure
#     through one hole instead of three.
#   - the DC bus feeds one contiguous 210 deg block from the power link at its
#     edge, rather than reaching around the board past the CPU.
#
# Cell width is unchanged at 70 deg, so nothing inside a cell had to move.
PHASE_SPAN   = 68.0          # deg. 67 is the floor: below it the DC-link row
                             # runs into the perimeter boss and the wedges lose
                             # their corners. The three cells were 60 while the
                             # small parts lived in the channel; routing showed
                             # that only GND and phase-output parts can get out
                             # of there, so five per cell came back in and the
                             # cells had to pay for them. It costs the even bolt
                             # circle -- see PERIM_ANG below.
# The three wedges get equal shares of what the phase cells leave. Splitting
# them unevenly was tried, because the power link is four parts and the CPU
# wedge twenty-six: it is worth almost nothing. The six bolts sit ON the
# section boundaries, so narrowing a wedge walks its own two bosses inward and
# its parts have to dodge them -- the power link needs 50 deg of the 156 all by
# itself, and the most the CPU can be given is 56 instead of 52.
WEDGE_SPAN   = 120.0 - PHASE_SPAN

def _wedge_start(i):
    return 3 * PHASE_SPAN + WEDGE_SPAN * i

PHASE_ANG    = [PHASE_SPAN * (i + 0.5) for i in range(3)]
WEDGE_ANG    = [_wedge_start(i) + WEDGE_SPAN / 2 for i in range(3)]

# The six M2.5 sit on the six SECTION BOUNDARIES, so every section has one at
# each edge and every phase cell's heatsink land runs the full width between
# its own two bolts. That ties the bolt circle to the section widths: 60/60 was
# the one arrangement that made it regular, and 68/52 gives that up again.
# 0, 68, 136, 204, 256, 308.
PERIM_BC     = 59.0          # bolt circle diameter
PERIM_D      = 2.7           # clearance for M2.5
PERIM_ANG    = ([PHASE_SPAN * i for i in range(3)]
                + [_wedge_start(i) for i in range(3)])
PERIM_N      = len(PERIM_ANG)
ZONE_R0      = 17.0          # no part inboard of this, on either face

# The interconnect used to be described here as two nominal rectangles. It is
# now three real footprints in tools/placement.py -- two 2x5 power headers and
# one 2x14 signal header -- so the description and the thing cannot disagree.

# Encoder
MT6701_BODY  = (6.0, 5.0)    # SO-8 lead span x body depth
MAGNET_D     = 6.0           # diametric magnet, as the MT6701 datasheet recommends.
                             # Dia 8 x 2.5 put more than the part's 100 mT maximum
                             # on the die at the short end of the air-gap
                             # tolerance (sim P5, Q10); Dia 6 keeps it inside
                             # the 20-100 mT window over the whole of it.
MAGNET_KEEP  = 12.0          # keepout on the motor-facing side

# Stack. y = 0 is the motor rear face, +y away from the motor. Every gap here
# is DERIVED, not chosen: the standoff under board A is whatever the encoder
# chain adds up to. Change SHAFT_PROUD once the motor is known and the drawing,
# the numbers and the prose all move together.
SHAFT_PROUD  = 5.0           # shaft end above the motor rear face  [MOTOR-DEPENDENT]
MAGNET_T     = 2.5           # diametric magnet + holder cap
AIR_GAP      = 1.5           # MT6701 package face to magnet face; spec 1-3 mm
MT6701_T     = 1.75          # SO-8 body thickness, hanging below board A
PCB_T        = 1.6
GAP_AB       = 11.0          # board A parts + mated interconnect height
GAP_TOP      = 11.0          # board B connectors and bulk cans

STANDOFF_A   = SHAFT_PROUD + MAGNET_T + AIR_GAP + MT6701_T   # motor face -> board A
MOTOR_BODY   = 12.0          # drawn only, not a spec

# --------------------------------------------------- electrical design ----
# THE design point. Everything below is derived from it, so changing this one
# number moves the shunt, the copper, the interconnect and the heatsink
# together. 20 A is RMS per phase, CONTINUOUS -- the sense chain has to reach
# its PEAK, and the thermal path has to carry its loss.
BUS_V        = 60.0          # nominal bus
BUS_SILICON  = 80.0          # MOSFET and TVS class
FSW          = 20e3          # switching frequency
I_PHASE      = 20.0          # A RMS per phase, continuous  [DESIGN POINT]
I_PHASE_PK   = I_PHASE * 2**0.5                    # 28.3 A
I_PHASE_MEAN = 2 / 3.14159265 * I_PHASE_PK         # mean |i| over a cycle
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

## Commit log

2026-09-23 servodrive: boards A, B (outline) and S, generators, simulation, project pages
    First commit of the project, which was not under git before. Includes
    today's board S change: the two LMR38010 bucks get TI's design-point
    passives (SNVSC73B table 9-1, 400 kHz from a 48 V bus) in place of the
    sketch's small parts.
    - 12 V: 68 uH SWPA4030S680MT, 22 uF 1206 + 22 uF 1210 X7R out
    - 5 V: 33 uH SWPA4030S330MT, 3 x 22 uF 0805 out
    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
    [01_input.kicad_sch, 01_power_stage.kicad_sch, 02_control.kicad_sch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]
2026-09-24 Add a 3D board viewer to the project pages
    tools/export_3d.py exports each board through kicad-cli's GLB exporter and
    rewrites the result for the web: primitives merged per mesh and material
    (~32,000 draw calls -> 317/459), positions quantized to 16 bits
    (KHR_mesh_quantization), board meshes welded without normals, KiCad's sRGB
    colours converted to glTF's linear, the mask translucent. 23.6 -> 5.2 MB for
    board A, 30.2 -> 6.8 MB for board S; same bytes for the same board. Three
    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
    [AOTA-B201610SR47MT.STEP, HRO_TYPE-C-31-M-12.step]
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2026-09-24 Part pane: the LCSC number, linked to LCSC and JLCPCB
    hardware/parts/lcsc.csv holds the LCSC numbers the project has chosen, by
    value and footprint as the board files write them -- the eleven already
    decided in the README's sourcing notes (EG2103, BSC030N08NS5, LMR38010, the
    two SWPA4030S inductors, board S's buck ceramics, the C2887236 cans), each
    checked against both sites. export_3d.py joins it into <board>.parts.json;
    a footprint's own LCSC field, if the schematic ever gets one, wins.
    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
    [lcsc.csv]
2026-09-24 Every placed part gets an LCSC number; 3D inductors and part colours fixed
    LCSC (hardware/parts/lcsc.csv, 76 rows): every part the assembler places on
    boards A (120) and S (173) now has a number, joined into the 3D part pane.
    Chosen from the sister board's BOM where it had the part, JLC basic parts
    where the rating allowed, each matched to the net it sits on and checked
    against JLCPCB's library (model, package, rating, stock) on 2026-09-24. The
    notes say why where it was not obvious: 100 V X7R/C0G on VBUS, 0.1% thin
    film for the dividers, a Vishay WSL metal-strip jumper for phase C's 0R
    (75 A, where a thick-film 0R carries a few), a CL 20 pF crystal for the
    27 pF caps, the RGB LED placed rot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
    [01_power_stage.kicad_sch, 02_control.kicad_sch, L_Sunlord_SWPA4030S.step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]
2026-09-24 Board S: bus on an XT30, set back from the edge; SIT3088s tidied; re-routed
    J4 is now the rp2350-motor-controller's XT30 (AMASS XT30PW-M, C431092,
    pin 1 GND, pin 2 VMOT) in place of the two bus pads. At the rim its pegs
    land on both RS-485 ports and no other rim takes a JST SH, so it sits 5 mm
    back with the plug's path kept clear; its pins land at R 14.5.
    - placement_s: bus="xt30" arrangement; the XT30 placed by its body with a
    peg rule; C1001 to 135 deg; SMDJ54A under the XT30; SM712 stacks; the four
    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
    [04_power.kicad_sch, XT30PW-M.STEP, lcsc.csv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]
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2026-09-24 Board S page: what the simulation says, and the board as it is now
    Below the PCB/3D viewer, a section generated by the simulation
    (phases/p9s_summary.py): each question graded against its criterion,
    the stat tiles, and the figures. Everything below it is rewritten for
    an engineer new to the board: ratings, a power tree, start-up/reset and
    protection, the floorplan, connector pinouts, the RP2350 pin map, the
    stackup and rules, build status (counted off the board by regen.py),
    open items and the parts table. The history of how it got here is gone
    from the page; the README keeps it.
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2026-09-25 Board S: screw keepouts, finer In3 centre rules, encoder on SPI0 (WIP, unrouted)
    Work in progress from 2026-09-24/25, saved before routing is finished.
    The board file here is the generator's output, not a routed board.
    - Keepouts on F.Cu and B.Cu round the four centre motor screws
    - USB-C placed tangent to the edge
    - Encoder on SPI0 (ENC_DO GPIO4, ENC_SCK GPIO6); J13 pins swapped
    - C901 moved north; encoder stitching vias back in the chip's pads
    - "fine centre" rule area: signal nets on In3 inside R 17 may use
    0.12 mm track and clearance (servodrive_S.kicad_dru); finish.py's
    maze tries 0.12 there when 0.15 fails; the area is stripped before
    the DSN export so freerouting doesn't see it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
    [02_control.kicad_sch, 05_io.kicad_sch, servodrive_S.kicad_pcb]
2026-09-26 fanout.taps: no sliver where a pad joins a neighbour's tap
    J13's pin swap put EXP_GP24 on the pad above the MT6701's pin 2, so
    that pin lost its via-in-pad and linked to pin 1's tap via instead: two
    +3V3 tracks meeting at 19.8 degrees, a copper sliver in KiCad's DRC.
    A link that would arrive at a via at 2-20 degrees to a track running
    from it to one of the net's pads now goes straight to that pad. On
    board S that changes U10 pins 1-2 and one +3V3 pair at (157.8, 94.2)
    (11.6 degrees); board A's fan-out is unchanged.
    [servodrive_S.kicad_pcb]
2026-09-26 Board S schematic: drawn as a person would draw it
    The sheets were a grid of parts with a stub and a label on every pin.
    tools/schdraw.py now draws a netlist from a hand-written layout: parts
    placed and turned, wires between the pins that belong together, T-joins
    split with a junction dot, ground and supply symbols on power pins, labels
    only where a signal leaves its block. tools/schlayout_s.py is board S's
    five sheets: signal left to right, supplies up, ground down, each part's
    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
    [01_power_stage.kicad_sch, 02_control.kicad_sch, 03_encoder.kicad_sch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]
2026-09-26 Board S schematic: the header and the notes follow the netlist
    J13's pins are drawn by net (VBUS row, ground row, supply pins on staggered
    stubs, labels for the rest), and the encoder note reads its GPIOs off U7, so
    the same layout draws main's pin map and this branch's.
    [02_control.kicad_sch, 03_encoder.kicad_sch, 05_io.kicad_sch]
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2026-09-26 Board S schematic: drawn as a person would draw it, and on the page
    support parts at the pin they serve, dashed frames and notes. The header
    pins and the notes follow the netlist, so a pin-map change redraws itself.
    The drawing cannot change the circuit: every sheet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
    [01_power_stage.kicad_sch, 02_control.kicad_sch, 03_encoder.kicad_sch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]
2026-09-27 Board S: GATE_OFF and FAULT_n to GPIO2/3, port OUT's PIO UART to 14/15 (unrouted)
    On GPIO14/15, GATE_OFF and FAULT_n left the RP2350 on the side facing away
    from Q1001 and R705; with keepouts round the motor screws that side's
    corridor was one track short, and every router and rip-up left one of
    GATE_OFF, FAULT_n, RUN or LED_R open. GPIO0-3 are the pads nearest Q1001,
    and port OUT's transceivers sit on 14/15's side. A PIO UART takes any
    pins; GPIO2 is pulled down through reset as 14 was, so the gate rail still
    comes up braking.
    Board regenerated, not yet routed. Netlist check, KiCad netlist export and
    ERC clean.
    [02_control.kicad_sch, servodrive_S.kicad_pcb]
2026-09-27 Board S routed with GATE_OFF/FAULT_n on GPIO2/3: 0 unconnected, DRC 0
    route.py --rounds 1 --first EN_12V,USB_VBUS,LIN_A,EXP_GP19,EXP_GP22 left one
    connection, ENC_OUT; a targeted rip-up (ENC_DO and RS485_IN_DN_P out of the
    way, ENC_OUT made, both made again) closed it. The router's +5V via beside
    the 5 V buck's SW link was 0.24 mm from it against the Phase class's 0.4:
    moved 0.3 mm clear. Dangling vias dropped, polished.
    1958 track segments, 418 vias; DRC 0 at every severity, 0 unconnected;
    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
    [servodrive_S.kicad_pcb]
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2026-09-27 route.py: halos round the demoted 60 V-class tracks, not only their pads
    A net complete before the router starts is demoted: its pads get a halo
    grown to the Phase class's 0.4 mm, its vias a grown keepout, but its
    tracks stayed as protected wiring on a net that no longer exists, and
    freerouting kept only its default 0.16 from them. The buck switch nodes
    are the case -- the fan-out lays U12's SW to L1002, SW_5V is complete
    before routing, and the router put a +5V via 0.24 mm from that link in two
    runs out of two. track_halos() gives each such track the pads' halo, for
    the nets the round actually demotes (a halo round a net still being
    routed would keep the router off its own copper).
    Tested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
    [route.py]
2026-09-27 Board S schematic on three sheets: bridge + CPU, power, encoder + IO
    Asked for fewer pages: the power bridge goes with the CPU that drives it
    (A2), the encoder with the rest of the IO (A3); the supplies keep their
    sheet. schematic_s.SHEET_OF maps the parts' sheet names (board A keeps its
    own), and schdraw.Sheet.origin() lets a sheet place layouts written in their
    own coordinates side by side. HIN/LIN and the other CPU-to-bridge nets are
    now local labels on one sheet. The notes say which sheet a part is on.
    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
    [01_bridge_cpu.kicad_sch, 01_power_stage.kicad_sch, 02_control.kicad_sch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]
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2026-09-29 Board S bulk as a choice of banks; six D6.3 cans swapped into the board as built
    schematic_s.BULK_VARIANTS / BULK_KIND pick the bank (2 x D10, 3 x D8, 5 or
    6 x D6.3) and placement_s.BULK_SITES where each can goes in the three
    pockets between the M3 heads. Six D6.3 are placed by _swap_bulk: the board
    as routed with two D10, the six put in at the spots that displace fewest
    parts, and only those 16 placed again near where they were -- placing the
    cans first re-flowed some sixty parts and the board would not route.
    The In2 fingers, the power sheet and the simulation follow the netlist's
    bank (sim/lib/board.bulk_s; P5S takes n cans). PA100V22M6X9 and SH476M100F1150
    models and LCSC rows. The powe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
    [lcsc.csv]
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2026-10-03 Viewer rebuilt with pcbview: pinch zoom, mobile tab bar fix
2026-10-16 Board S simulation: Q11 radiated field and the Q1 cross-check rebuilt
    Q11 now runs and converges: phase A's switch node driven against ground
    at the low-side FET (every other net AC ground at 30 MHz-1 GHz), a DC-free
    Gaussian-derivative pulse, the mesh snapped to copper only around the
    switch node, and the far field integrated over the whole sphere in degrees
    (CalcNF2FF wants degrees; the old run passed radians). 56 dBuV/m at 3 m per
    volt at the 115 MHz ring with a 58 mm lead; two meshes agree to 0.5 dB, and
    a 60 mm dipole known-answer test checks the transform. geom_export no longer
    drops a third of the In1/In4 ground planes when splitting holed polygons.
    Q1: the FETs are footprint fills w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
2026-10-16 Board S: SIT65HVD75ETK and W25Q80DVUXIE for the parts that went out of stock
    Every placed part re-checked at JLCPCB on 2026-10-16: the SIT3088ETK and
    the W25Q16JVUXIQ were at zero. The SIT65HVD75ETK is the same MAX3485
    pinout in the same DFN-8 3x3 (C7433976, 20,671 in stock), and its receiver
    threshold (V_IT+ <= -10 mV) reads a terminated idle pair as a 1, which
    answers the fail-safe item on paper. The W25Q80DVUXIE is the same pins and
    USON 2x3 land pattern, 8 Mbit (C401667, 8,611): firmware needs
    PICO_FLASH_SIZE_BYTES 1 MB and has to set QE, which it ships clear.
    Board S only (schematic_s overrides; board A keeps the W25Q16JV): two new
    derived symbols appended to the library, the two sheet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
